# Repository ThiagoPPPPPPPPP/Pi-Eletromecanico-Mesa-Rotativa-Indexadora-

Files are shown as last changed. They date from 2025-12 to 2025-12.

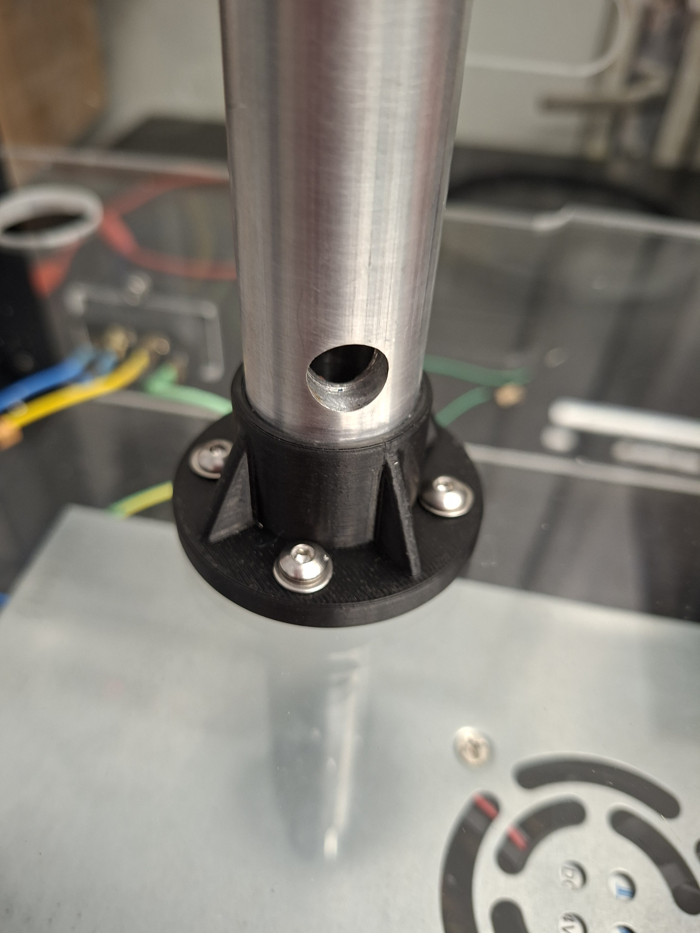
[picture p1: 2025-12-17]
Manual de Montagem/20251208_164349.jpg

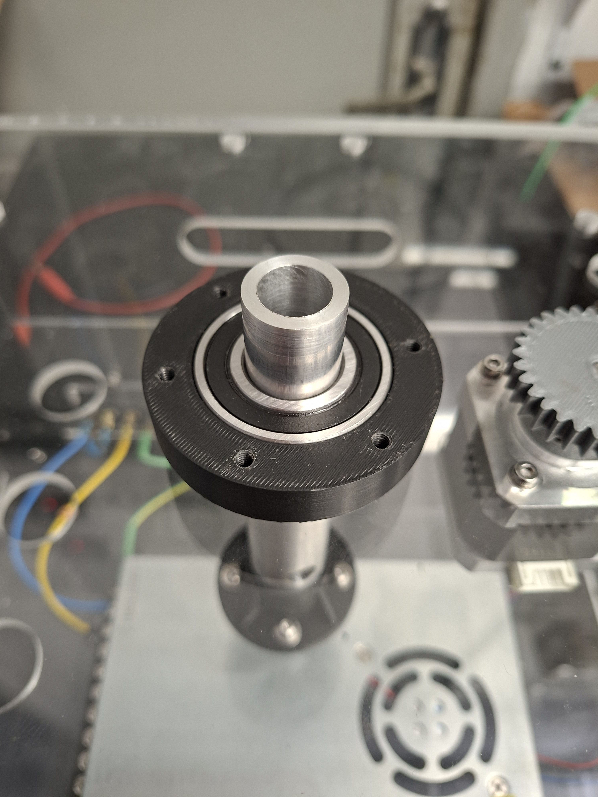
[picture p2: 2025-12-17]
Manual de Montagem/20251208_165738.jpg

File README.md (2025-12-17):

# Mesa Giratória Indexadora - Módulo de Ensino de Mecatrônica

Este repositório contém a documentação e os arquivos de projeto da **Mesa Giratória Indexadora**, um módulo de ensino desenvolvido para auxiliar na formação prática de alunos sobre integração de sistemas automatizados.

O projeto integra mecânica, eletrônica e programação para simular um processo industrial de indexação, detecção,  separação de peças ou possíveis operações em peças já catalogadas.

---

## 📖 Sobre o Projeto

A **Mesa Giratória Indexadora** foi projetada como um recurso pedagógico para demonstrar princípios de automação industrial, incluindo:
* Controle de posicionamento preciso.
* Sensoriamento e identificação de materiais.
* Atuação eletromecânica.
* Lógica de comando sequencial.

O sistema opera com uma tensão de segurança (5V a 24V) e possui uma estrutura transparente (acrílico) para permitir a visualização clara dos componentes e do funcionamento interno durante as aulas.

### ⚙️ Funcionalidades
* **Indexação Automática:** Movimentação da mesa em 6 posições fixas com parada precisa.
* **Detecção de Material:** Identificação de peças metálicas e não-metálicas (plástico) utilizando sensores indutivos e capacitivos.
* **Sistema de Expulsão:** Atuador solenoide customizado para remover peças da linha de produção após o processamento.
* **Interface Visual:** Feedback de status dos sensores e etapas do ciclo através de LEDs.
* **Segurança:** Operação em baixa tensão e botão de emergência.

---

## 🛠️ Hardware e Arquitetura

O projeto utiliza uma arquitetura dividida em **Nível Inferior** (Controle e Potência) e **Nível Superior** (Atuação e Processamento).

### Componentes Eletrônicos Principais
* **Controlador:** Arduino Mega 2560 R3.
* **Shield PLC:** Placa de adaptação DNMEB50 da eletechsup.
* **Atuadores:**
    * Motor de Passo NEMA 17.
    * Driver de Motor TB6600.
    * Solenoide Customizada (Ejeção).
    * Cooler 12V para refrigeração da eletrônica.
* **Sensores:**
    * Sensores Indutivos (Detecção de metal).
    * Sensores Capacitivos (Detecção de presença/não-metal).
* **Alimentação:** Fonte Chaveada 24V/15A.

### Estrutura Mecânica
* **Base e Caixa:** Acrílico 6mm (Corte a Laser).
* **Mesa Giratória:** Acrílico 4mm.
* **Peças de Suporte:** Impressão 3D (ABS) para suportes de sensores, solenoide e engrenagens.
* **Transmissão:** Sistema de Pinhão e Engrenagem Interna com redução 1:5.

---

## 💻 Software e Lógica

O firmware foi desenvolvido em **C++ (Arduino)** e implementa uma máquina de estados para controlar o ciclo da máquina:

1.  **Detecção:** Aguarda peça na estação de entrada.
2.  **Identificação:** Lê sensores para classificar o material (Metal/Não Metal).
3.  **Movimentação:** Aciona o motor de passo para avançar a mesa para a próxima estação.
4.  **Expulsão:** Ao chegar na estação de saída, ativa a solenoide se a peça for confirmada.
5.  **Feedback:** Atualiza os LEDs indicadores de status em tempo real.

---

## 📦 Como Reproduzir

### Pré-requisitos
* Arduino IDE instalado.
* Bibliotecas padrão do Arduino.

### Instalação
1.  Clone este repositório:
    ```bash
    git clone [https://github.com/ThiagoPPPPPPPPP/Pi-Eletromecanico-Mesa-Rotativa-Indexadora-.git](https://github.com/ThiagoPPPPPPPPP/Pi-Eletromecanico-Mesa-Rotativa-Indexadora-.git)
    ```
2.  Abra o arquivo principal do código (ex: `Mesa_Indexadora.ino`) na Arduino IDE.
3.  Conecte o Arduino Mega via USB.
4.  Selecione a placa **Arduino Mega or Mega 2560** no menu de ferramentas.
5.  Faça o upload do código.

> **Nota:** Consulte o arquivo `Manual de Montagem.pdf` para o passo a passo da montagem mecânica e o esquema elétrico detalhado no arquivo do relatório.

---

## 👥 Autores

Projeto desenvolvido por alunos do curso de **Engenharia Mecatrônica** do **IFSC - Câmpus Florianópolis**:

* **Gabriel Vitor Salasario Boing**
* **Jorge Henrique Martins de Oliveira Chaves**
* **Sarah Even Oliveira Barbosa Fernandes**
* **Thiago Paulo Pohlenz Piccoli de Oliveira**

---

## 🏫 Instituição

**Instituto Federal de Santa Catarina (IFSC)**
Departamento Acadêmico de Metal Mecânica
Florianópolis - 2025

---

*Este projeto é de cunho educacional e open-source.*

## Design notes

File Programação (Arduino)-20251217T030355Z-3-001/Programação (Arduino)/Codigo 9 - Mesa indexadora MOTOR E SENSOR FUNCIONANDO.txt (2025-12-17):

#include <Arduino.h>

// ======================================================
//                    MESA INDEXADORA 
// ======================================================

//V18 CAPACITIVO SAIDA
//V15 INDUTIVO ENTRADA
//V17 CAPACITIVO ENTRADA
//V16 INDUTIVO SAIDA

// ================================
//       SENSORES IND + CAP 
// ================================
#define SENIND1 66
#define SENIND2 67
#define SENC1   68
#define SENC2   69

// ================================
//               LEDS
// ================================
#define LED1 34
#define LED2 36
#define LED3 38
#define LED4 40

// ================================
//         SOLENOIDE 
// ================================
//#define CARGA    41
//#define TRIGGER  39

// ================================
//             MOTOR
// ================================
#define STEP_PIN   41
#define DIR_PIN    39
#define PASSOS_POR_POSICAO 1333
#define VELOCIDADE_US 800

// ================================
//           VARIÁVEIS
// ================================
bool pecas[6] = {0,0,0,0,0,0};
bool mesaLigada = false;
bool cicloAtivo = false;

unsigned long marcaTempo = 0;
const unsigned long tempoEtapa = 4000;

int v15 = 0, v16 = 0, v17 = 0, v18 = 0;

// forward declarations
void desligarTudo();
bool detectarPecaEntrada();
void ligarMesa();
void cicloIndexador();
int leituraMaterialEntrada();
int leituraMaterialSaida();
void expulsarPeca();
void finalizarCiclo();
void moverPosicao();
void moverEtapa(int pos);
void exibirStatus();
void IHM();

// ======================================================
//                     SETUP
// ======================================================
void setup() {
  Serial.begin(9600);
  delay(50);

  pinMode(SENIND1, INPUT);
  pinMode(SENIND2, INPUT);
  pinMode(SENC1, INPUT);
  pinMode(SENC2, INPUT);

  pinMode(LED1,OUTPUT);
  pinMode(LED2,OUTPUT);
  pinMode(LED3,OUTPUT);
  pinMode(LED4,OUTPUT);

  pinMode(CARGA,OUTPUT);
  pinMode(TRIGGER,OUTPUT);

  pinMode(STEP_PIN,OUTPUT);
  pinMode(DIR_PIN,OUTPUT);

  desligarTudo();
  Serial.println("==== SISTEMA PRONTO ====");
}

// ======================================================
//                        LOOP
// ======================================================
void loop(){  

  IHM();

  if(!mesaLigada && detectarPecaEntrada()){
      ligarMesa();
  }

  if(mesaLigada && cicloAtivo){
      cicloIndexador();
  }
}

// ======================================================
//              DETECTA PEÇA NA ENTRADA
// ======================================================
bool detectarPecaEntrada() {

  bool cap = digitalRead(SENC1);        // capacitivo
  bool ind = !digitalRead(SENIND1);      // indutivo

  if(cap == HIGH || ind == HIGH){       // qualquer um detectou → peça presente
      pecas[0] = 1;

      Serial.print("\n📥 Peça detectada na ENTRADA: ");

      if(ind == HIGH){
          Serial.println("METAL");
      } 
      else if(ind == LOW && cap == HIGH){
          Serial.println("NAO METAL");
      }
      else {
          Serial.println("SEM LEITURA");
      }

      return true;
  }

  return false;
}

// ======================================================
//                   LIGAR MESA
// ======================================================
void ligarMesa(){
  Serial.println("\n▶ Iniciando ciclo...");
  mesaLigada = true;
  cicloAtivo = true;
  marcaTempo = millis();
}

// ======================================================
//                   CICLO COMPLETO 
// ======================================================
void cicloIndexador(){
  static int etapa = 0;

  if(millis()-marcaTempo < tempoEtapa) return;
  marcaTempo = millis();

  switch(etapa){
    case 0:
      moverEtapa(1); 
      break; 
    case 1:
      moverEtapa(2); 
      break; 
    case 2:
      moverEtapa(3); 
      break;
    case 3:
      moverEtapa(4);
      break;
    case 4:
      moverEtapa(5);

      // → POSIÇÃO 6 (Saída)
      expulsarPeca();  
      finalizarCiclo(); 
      etapa = 0;
      return;

    default:
      etapa=0; 
      return;
  }

  etapa++;
}

// ======================================================
//       LEITURA DO MATERIAL NA SAÍDA (POSIÇÃO 6)
// ======================================================
int leituraMaterialSaida(){

  bool cap = digitalRead(SENC2);
  bool ind = !digitalRead(SENIND2);

  if(ind == HIGH){
     Serial.println("📦 Saída → METAL");
     return 1;
  } 
  else if(ind == LOW && cap == HIGH){
     Serial.println("📦 Saída → NAO METAL");
     return 2;
  }
  else {
     Serial.println("📦 Saída → SEM PEÇA");
     return 0;
  }
}

// ======================================================
//                EXPULSÃO FINAL
// ======================================================
void expulsarPeca(){

  Serial.println("\n⏳ Checando peça na posição final...");

  int material = leituraMaterialSaida();

  bool cap = digitalRead(SENC2);
  bool ind = !digitalRead(SENIND2);

  if(cap == HIGH || ind == HIGH){
    Serial.println("✔ Peça confirmada na SAÍDA. Acionando solenoide...");

    digitalWrite(CARGA, HIGH);
    delay(150);
    digitalWrite(TRIGGER, HIGH);
    delay(150);
    digitalWrite(TRIGGER, LOW);
    digitalWrite(CARGA, LOW);

    Serial.println("➡ Peça expulsa.");
  } 
  else {
    Serial.println("⚠ Nenhuma peça encontrada para expulsar.");
  }
}

// ======================================================
//                   FINALIZAR CICLO
// ======================================================
void finalizarCiclo(){
  Serial.println("\n✔ Ciclo completo. Sistema aguardando nova peça.");
  cicloAtivo=false;
  mesaLigada=false;
  desligarTudo();
}

// ======================================================
//                   MOTOR — 1 POSIÇÃO
// ======================================================
void moverPosicao(){
  digitalWrite(DIR_PIN,LOW);
  for(int i=0;i<PASSOS_POR_POSICAO;i++){
    digitalWrite(STEP_PIN,HIGH); delayMicroseconds(VELOCIDADE_US);
    digitalWrite(STEP_PIN,LOW);  delayMicroseconds(VELOCIDADE_US);
  }
}

// desloca vetor de posição
void moverEtapa(int pos){
  moverPosicao();
  for(int i=5;i>0;i--) pecas[i] = pecas[i-1];
  pecas[0]=0;
  Serial.print("\n➡ Mesa avançou para posição ");
  Serial.println(pos+1);
  exibirStatus();
}

// ======================================================
//              MOSTRAR STATUS NO SERIAL
// ======================================================
void exibirStatus(){
  Serial.print("Estado da mesa: ");
  for(int i=0;i<6;i++){ Serial.print(pecas[i]); Serial.print(" "); }
  Serial.println();
}

// ======================================================
//                       IHM
// ======================================================
void IHM() {
  v15 = digitalRead(SENIND1);
  v16 = digitalRead(SENIND2);
  v17 = digitalRead(SENC1);
  v18 = digitalRead(SENC2);

  if (v15 != 1 && v16 == 1 && v17 == 0 && v18 == 0) {
    digitalWrite(LED1, LOW);
    digitalWrite(LED2, HIGH);
    digitalWrite(LED3, HIGH);
    digitalWrite(LED4, HIGH);
  } else if (v15 != 1 && v16 != 1 && v17 == 0 && v18 == 0) {
    digitalWrite(LED1, HIGH);
    digitalWrite(LED2, LOW);
    digitalWrite(LED3, HIGH);
    digitalWrite(LED4, HIGH);
  } else if (v15 == 1 && v16 == 1 && v17 != 0 && v18 == 0) {
    digitalWrite(LED1, HIGH);
    digitalWrite(LED2, HIGH);
    digitalWrite(LED3, LOW);
    digitalWrite(LED4, HIGH);
  } else if (v15 == 1 && v16 == 1 && v17 == 0 && v18 != 0) {
    digitalWrite(LED1, HIGH);
    digitalWrite(LED2, HIGH);
    digitalWrite(LED3, HIGH);
    digitalWrite(LED4, LOW);
  } else {
    digitalWrite(LED1, HIGH);
    digitalWrite(LED2, HIGH);
    digitalWrite(LED3, HIGH);
    digitalWrite(LED4, HIGH);
  }
}

// ======================================================
//             RESET EM TODAS SAIDAS/LEDS
// ======================================================
void desligarTudo(){
  digitalWrite(CARGA,LOW);
  digitalWrite(TRIGGER,LOW);
  digitalWrite(LED1,HIGH);
  digitalWrite(LED2,HIGH);
  digitalWrite(LED3,HIGH);
  digitalWrite(LED4,HIGH);
}

// ======================================================
//           MÓDULOS EM BRANCO PARA UPGRADES FUTUROS
// ======================================================
void moduloExtra1() {}
void moduloExtra2() {}
void moduloExtra3() {}
void moduloExtra4() {}
// ======================================================
// ======================================================

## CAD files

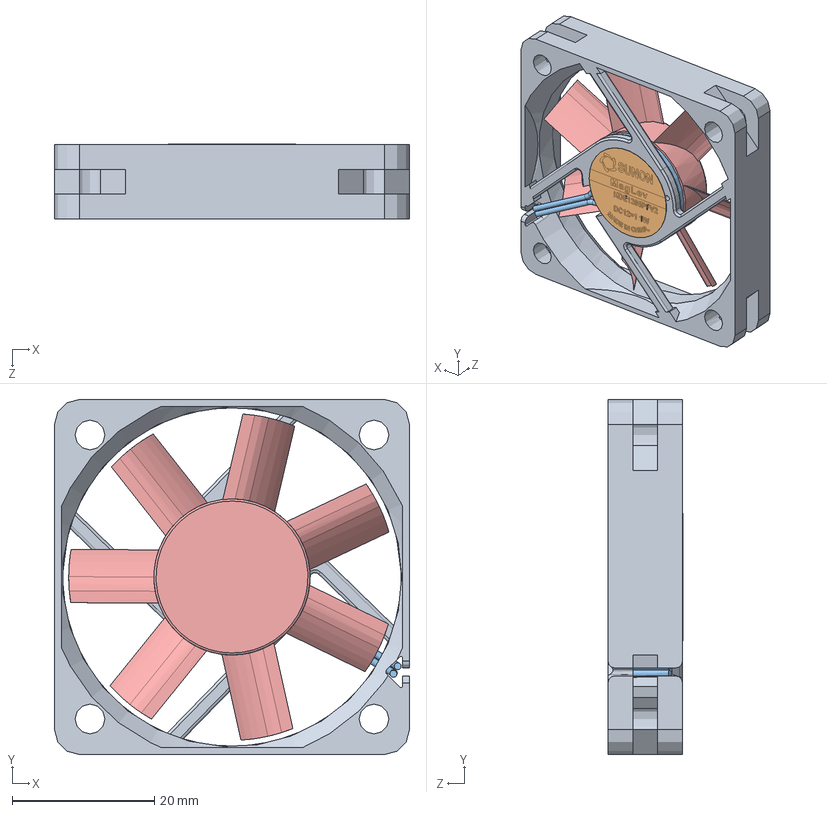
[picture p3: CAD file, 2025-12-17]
Arquivos CAD-20251217T030342Z-3-001/Arquivos CAD/Peças e Montagem Final/Cooler 50x50x10.5/Cooler 50x50x10.5 detailed SBORKA.SLDASM
50.0 x 50.0 x 10.6 mm
Cooler 50x50x10.5 body
Sticker SUNON
Cooler pcb
Cooler Motor
Cooler Blades

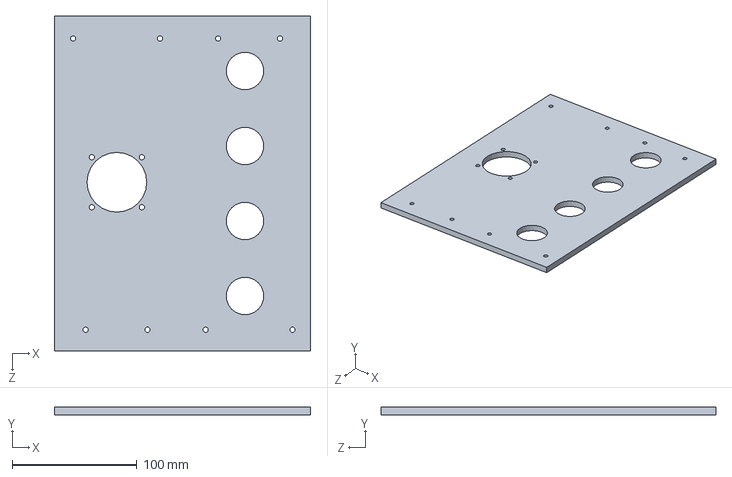
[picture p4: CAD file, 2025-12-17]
Arquivos CAD-20251217T030342Z-3-001/Arquivos CAD/Peças e Montagem Final/Caixa Parafusada/Lateral_cooler_parafusado.SLDPRT
205.0 x 6.00 x 268.0 mm

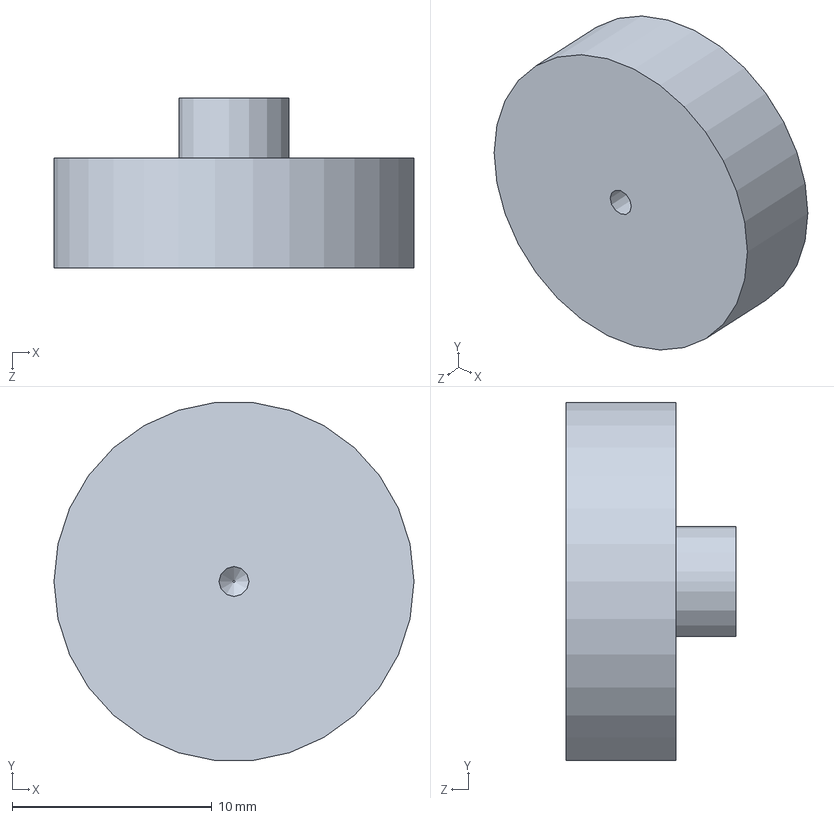
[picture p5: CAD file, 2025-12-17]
Arquivos CAD-20251217T030342Z-3-001/Arquivos CAD/Peças e Montagem Final/Cooler 50x50x10.5/Cooler Motor.SLDPRT
18.0 x 17.9 x 8.50 mm

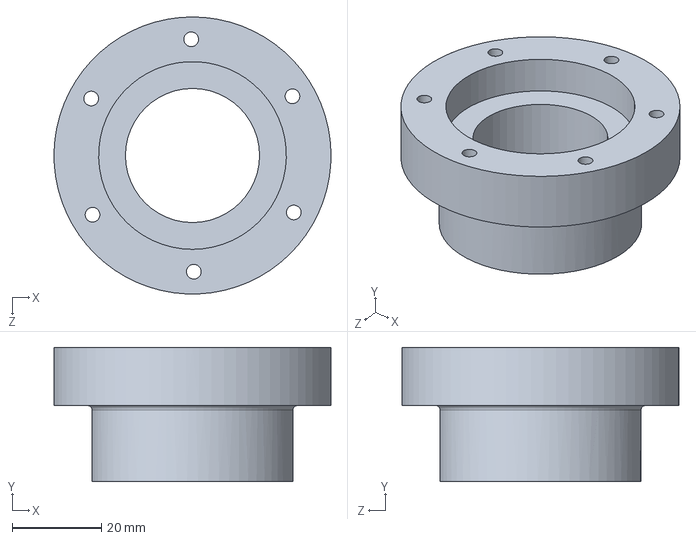
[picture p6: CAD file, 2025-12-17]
Arquivos CAD-20251217T030342Z-3-001/Arquivos CAD/Peças e Montagem Final/Mesa Giratória/Luva (mancal).SLDPRT
62.0 x 30.0 x 62.0 mm

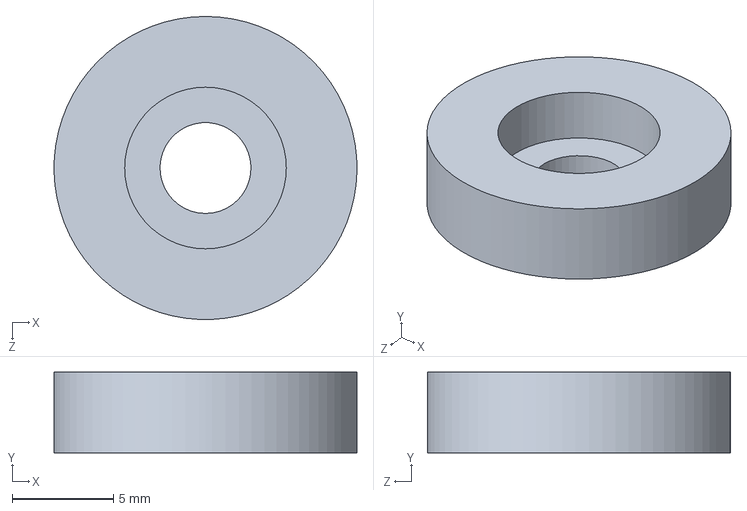
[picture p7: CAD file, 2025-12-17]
Arquivos CAD-20251217T030342Z-3-001/Arquivos CAD/Peças e Montagem Final/Caixa Parafusada/Pé_Fundo.SLDPRT
15.0 x 4.00 x 15.0 mm

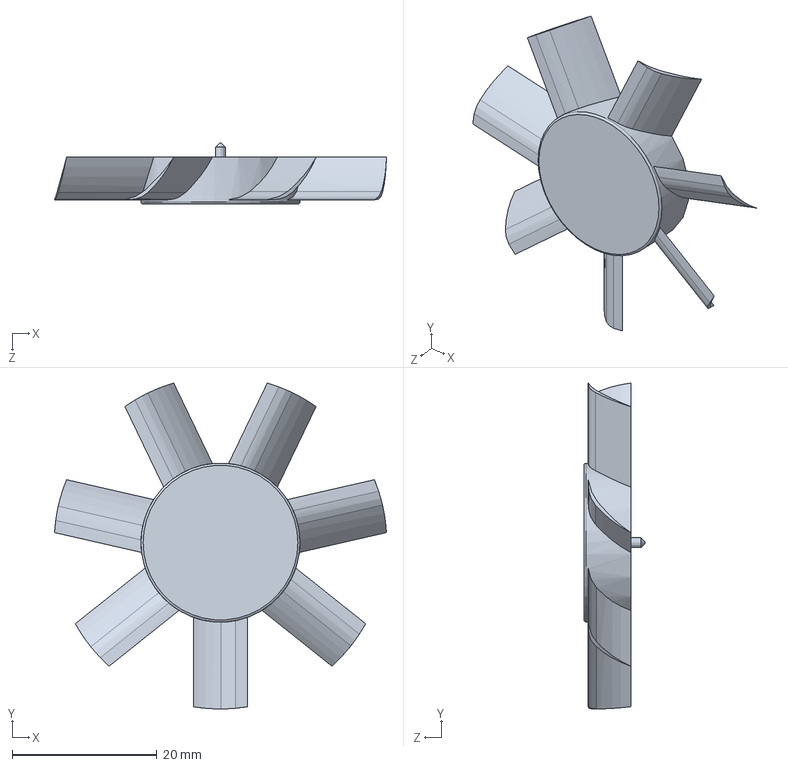
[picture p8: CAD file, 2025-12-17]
Arquivos CAD-20251217T030342Z-3-001/Arquivos CAD/Peças e Montagem Final/Cooler 50x50x10.5/Cooler Blades.SLDPRT
45.9 x 45.1 x 8.50 mm

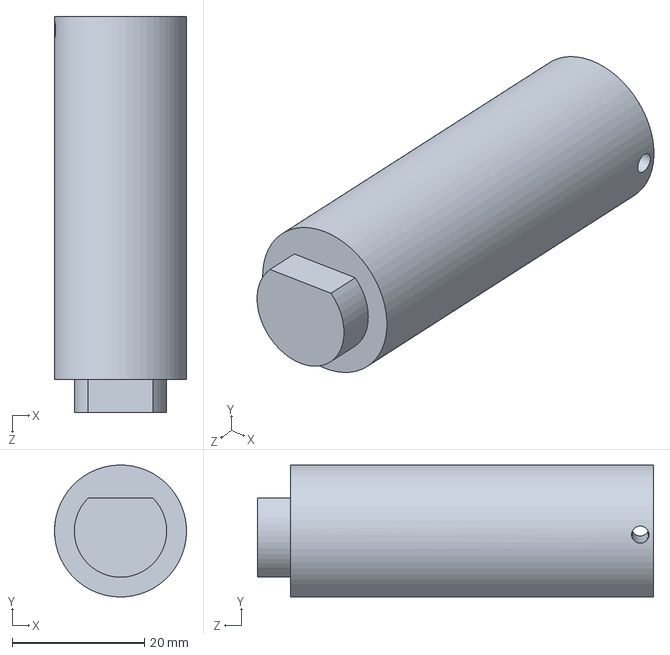
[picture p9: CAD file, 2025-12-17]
Arquivos CAD-20251217T030342Z-3-001/Arquivos CAD/Peças e Montagem Final/Embulo Solenoide.SLDPRT
20.0 x 20.0 x 60.0 mm

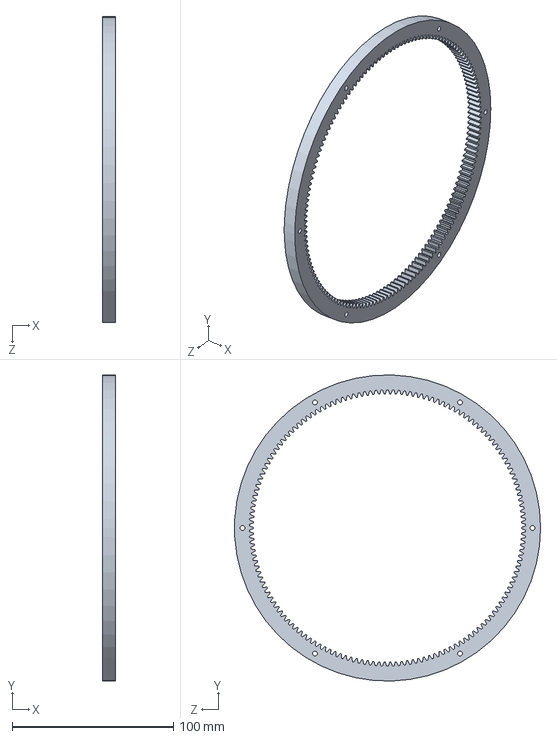
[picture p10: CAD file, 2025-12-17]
Arquivos CAD-20251217T030342Z-3-001/Arquivos CAD/Peças e Montagem Final/Mesa Giratória/Eng Interna M1.125 D150.SLDPRT
8.00 x 189.9 x 190.0 mm

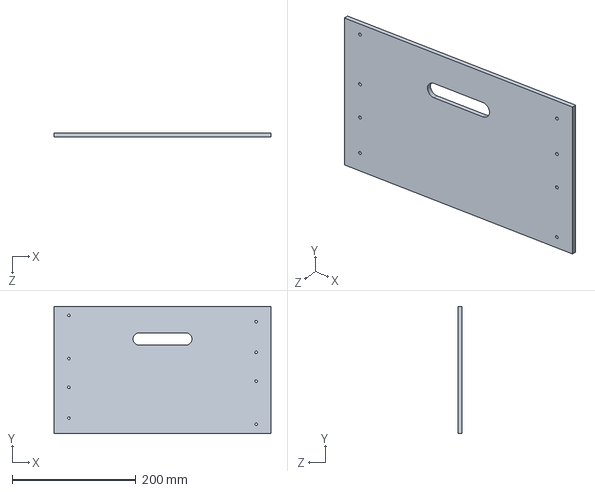
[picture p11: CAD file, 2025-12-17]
Arquivos CAD-20251217T030342Z-3-001/Arquivos CAD/Peças e Montagem Final/Caixa Parafusada/Frente-Back_parafusado.SLDPRT
350.0 x 205.0 x 6.00 mm

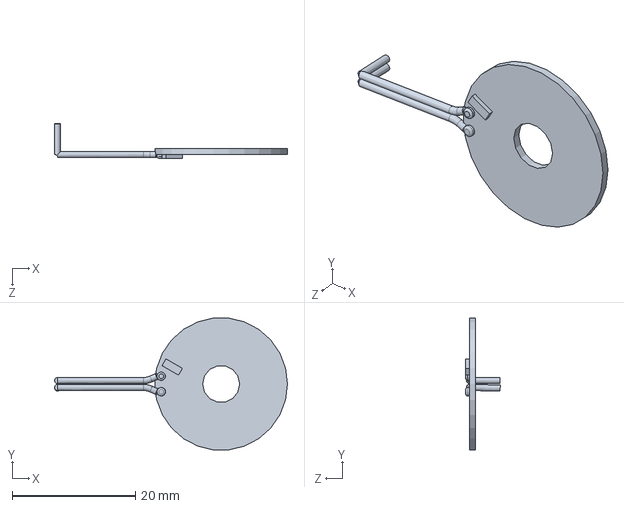
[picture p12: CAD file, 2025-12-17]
Arquivos CAD-20251217T030342Z-3-001/Arquivos CAD/Peças e Montagem Final/Cooler 50x50x10.5/Cooler pcb.SLDPRT
37.8 x 21.3 x 5.61 mm

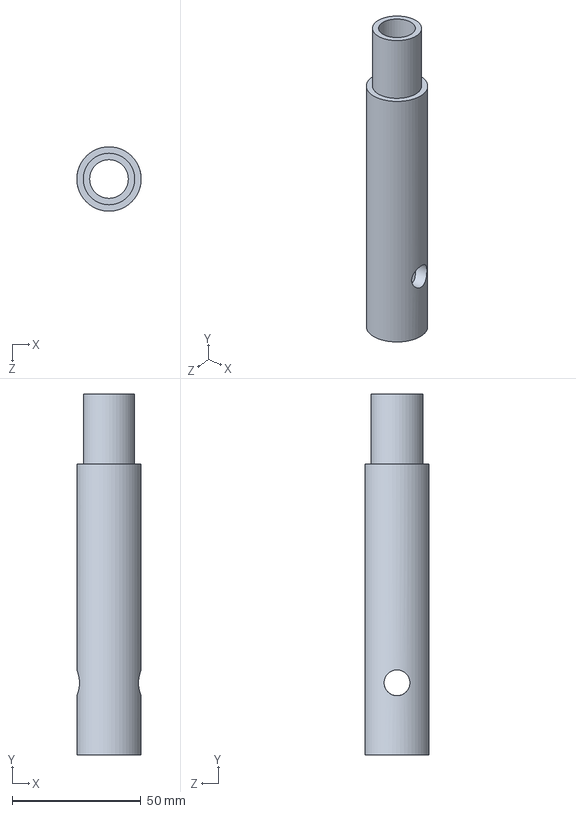
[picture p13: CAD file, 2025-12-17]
Arquivos CAD-20251217T030342Z-3-001/Arquivos CAD/Peças e Montagem Final/Mesa Giratória/Eixo.SLDPRT
25.0 x 140.0 x 25.0 mm

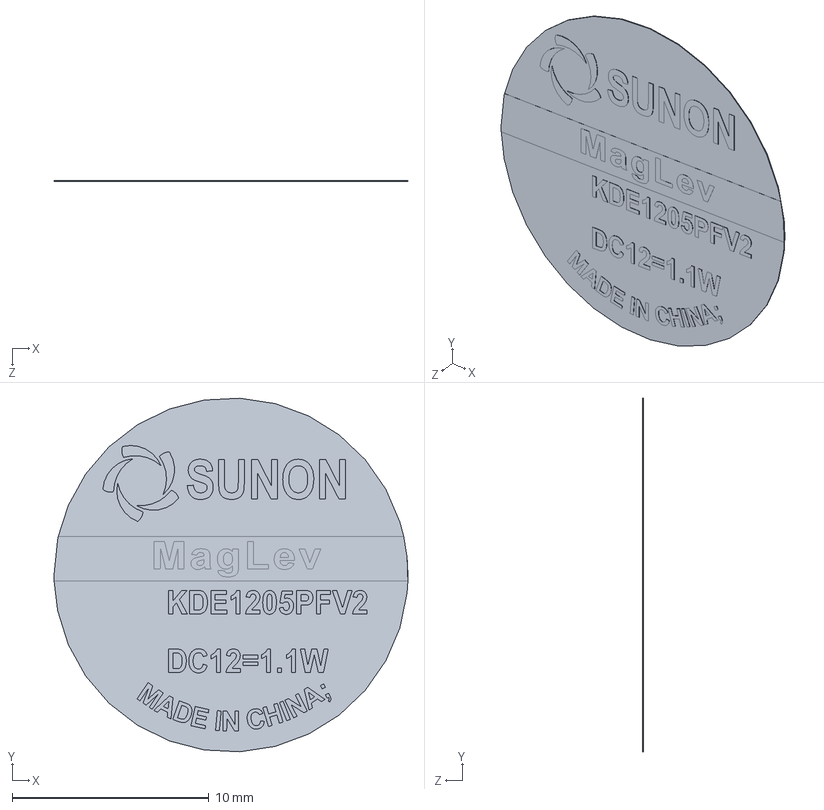
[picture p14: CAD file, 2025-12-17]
Arquivos CAD-20251217T030342Z-3-001/Arquivos CAD/Peças e Montagem Final/Cooler 50x50x10.5/Sticker SUNON.SLDPRT
18.0 x 18.0 x 0.07 mm

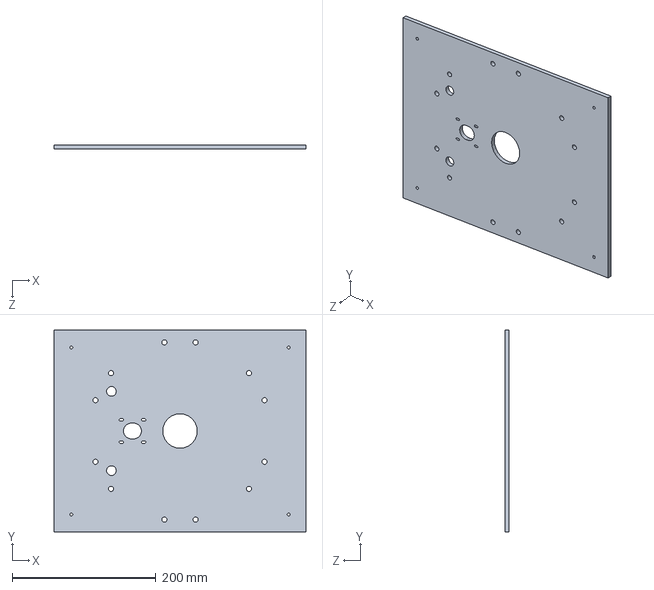
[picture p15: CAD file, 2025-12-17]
Arquivos CAD-20251217T030342Z-3-001/Arquivos CAD/Peças e Montagem Final/Caixa Parafusada/Top_parafusado.SLDPRT
350.0 x 280.0 x 6.00 mm

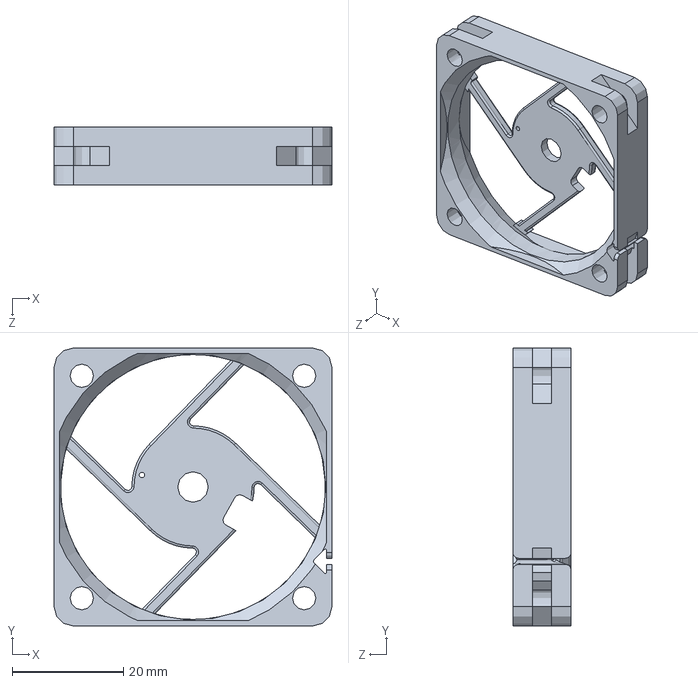
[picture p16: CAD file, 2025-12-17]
Arquivos CAD-20251217T030342Z-3-001/Arquivos CAD/Peças e Montagem Final/Cooler 50x50x10.5/Cooler 50x50x10.5 body.SLDPRT
50.0 x 50.0 x 10.5 mm

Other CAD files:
Arquivos CAD-20251217T030342Z-3-001/Arquivos CAD/Peças e Montagem Final/Caixa Parafusada/Mont_caixa_parafusada.SLDASM
Arquivos CAD-20251217T030342Z-3-001/Arquivos CAD/Peças e Montagem Final/Fonte 24V.SLDPRT
Arquivos CAD-20251217T030342Z-3-001/Arquivos CAD/Peças e Montagem Final/Caixa Parafusada/Frente-Back_parafusado_fonte.SLDPRT
Arquivos CAD-20251217T030342Z-3-001/Arquivos CAD/Peças e Montagem Final/Caixa Parafusada/Lateral_parafusado.SLDPRT
Arquivos CAD-20251217T030342Z-3-001/Arquivos CAD/Peças e Montagem Final/Anterior da Solenoide.f3d
Arquivos CAD-20251217T030342Z-3-001/Arquivos CAD/Peças e Montagem Final/Caixa Parafusada/1 andar.SLDPRT
Arquivos CAD-20251217T030342Z-3-001/Arquivos CAD/Peças e Montagem Final/Caixa Parafusada/Fundo_parafusado.SLDPRT
Arquivos CAD-20251217T030342Z-3-001/Arquivos CAD/Peças e Montagem Final/Caixa Parafusada/cantoneira2.SLDPRT
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

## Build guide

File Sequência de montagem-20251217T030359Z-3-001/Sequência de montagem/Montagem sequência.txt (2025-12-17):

Caixa componentes:

-Fundo_parafusado;
-Lateral_cooler_parafusado;
-Lateral parafusado;
-Frente-Back_parafusado;
-Frente-Back_parafusado_fonte;
-Top_parafusado;
-1 andar;
-Placa de controle;
-TB-6600;
-8 cantoneiras;
-Fonte 24V;
-Cooler;

Mesa componentes:

-Mesa inteira
-6 Ressalto Peça;
-Motor de passo;
-Luva(mancal);
-Rolamento;
-2 Sensores indutivos;
-Suporte eixo;
-Eixo;
-Solenoide
-Eng interna M1.125 D150;
-Pinhão m1.125 D30;
-Suporte solenoide com viga v2.step;

Montagem:

-Parte inferior:
1_ 4 cantoneiras entre parte media e base inferior;
2_ 20 parasusos M4 (4 para fixar Fundo_parafusado e cantoneira, 16 para fixar cantoneira e faces laterais);
3_ Fonte 24V;
4_ 2 parafusos diâmetro 4.2mm para fixar Fonte 24V na parte Frente-Back_parafusado_fonte;
5_ Cooler;
6_ 4 parafusos diâmetro 4.2mm para fixar Cooler na parte Lateral_cooler_parafusado;

-Parte média:
1_ 2 parafusos M4 para fixar cantoneira inferior->1 andar->cantoneira superior;
2_ 4 cantoneiras entre parte media e parte superior;
3_ 16 parafusos M4 para fixar cantoneiras as faces laterais ;
4_ Placa de controle;
5_ TB-6600;
6_ Eixo
7_ Suporte Eixo
8_ 4 parafusos M4 para fixar Suporte Eixo em 1 andar;

Mesa semi-completa:

1_ 12 parafusos M4 para fixar 6 ressalto peça em Mesa inteira;
2_ Rolamento
3_ 6 parafusos M4 para fixar Luva(mancal) em Mesa inteira;
4_ 6 parafusos M3 para fixar Eng interna M1.125 D150 em Mesa inteira;

-Parte superior:
1_ 2 parafusos M4 para fixar cantoneira superior->Top_parafusado;
2_ 2 sensores capacitivo (fixar no Top_parafusado pela porca do sensor com a furação da mesa);
3_ Motor de passo;
4_ Posicionar Suporte solenoide com viga v2.step no Eixo;
5_ 4 parafusos M3 para fixar Motor de passo no Top_parafusado;
6_ Posicionar Eng interna M1.125 D150 com pinhão m1.125 D30
7_ Posicionar Mesa inteira no Eixo;

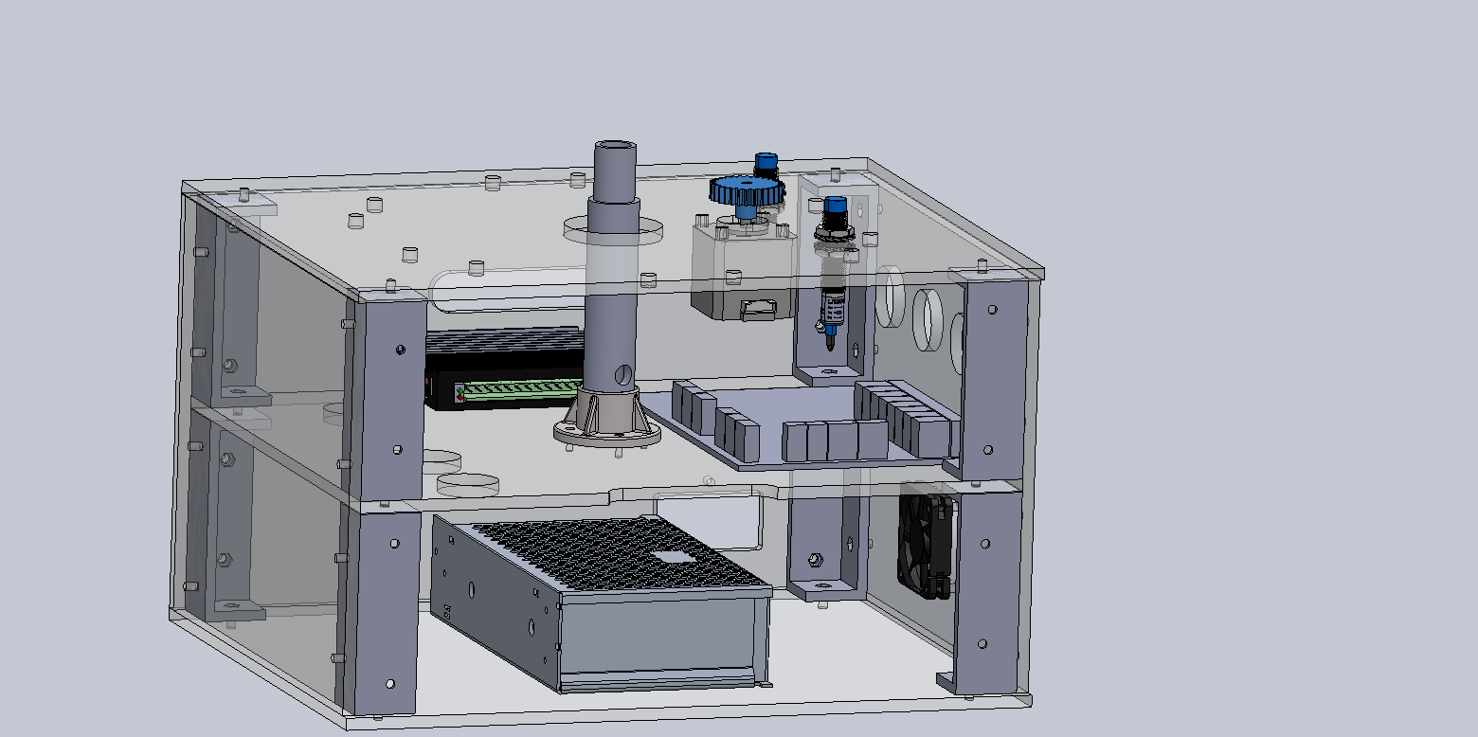
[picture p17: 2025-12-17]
Sequência de montagem-20251217T030359Z-3-001/Sequência de montagem/17-Posicionar e fixar o inhao m1.125 D30 no motor de passo.png

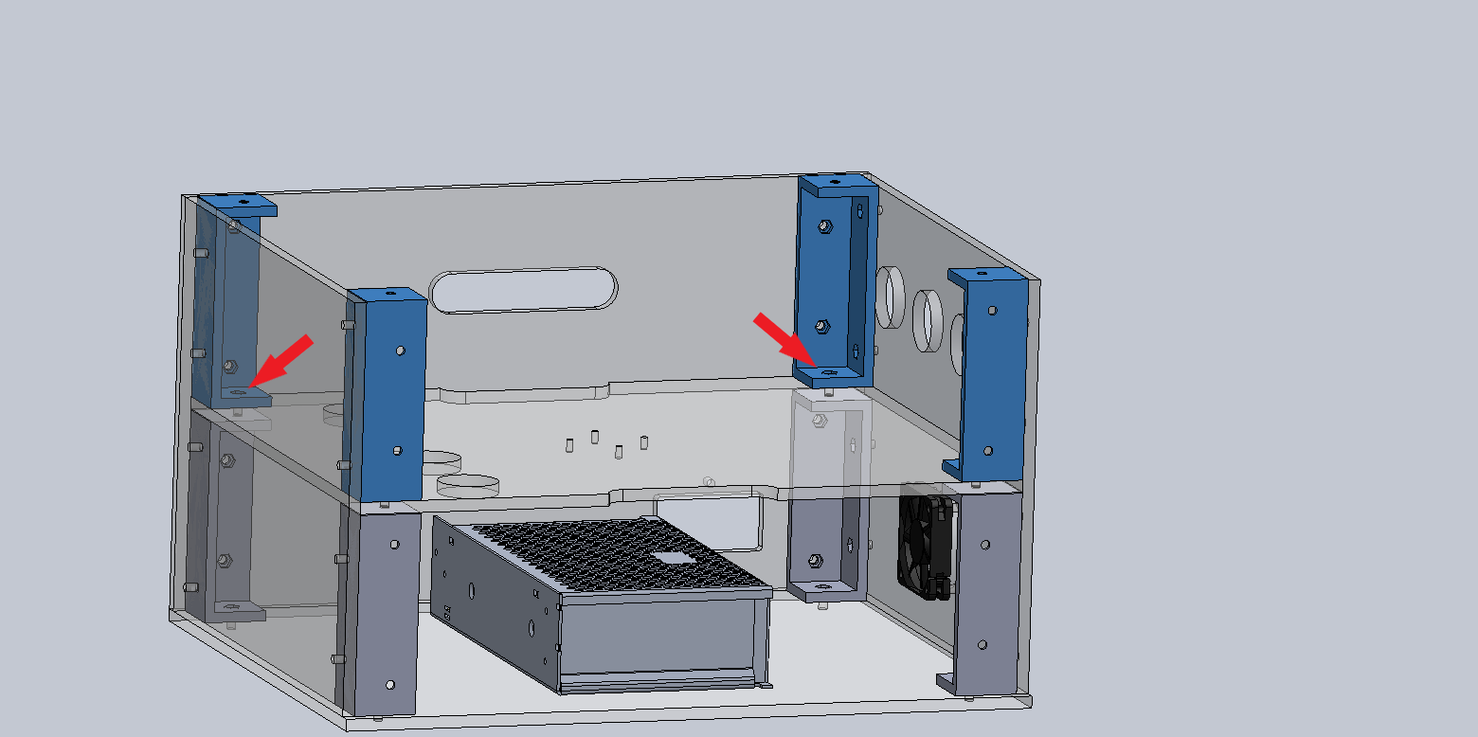
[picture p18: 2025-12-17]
Sequência de montagem-20251217T030359Z-3-001/Sequência de montagem/9-Posicionar e fixar as cantoneiras nas laterais e nas cantoneiras inferiores_Setas.png

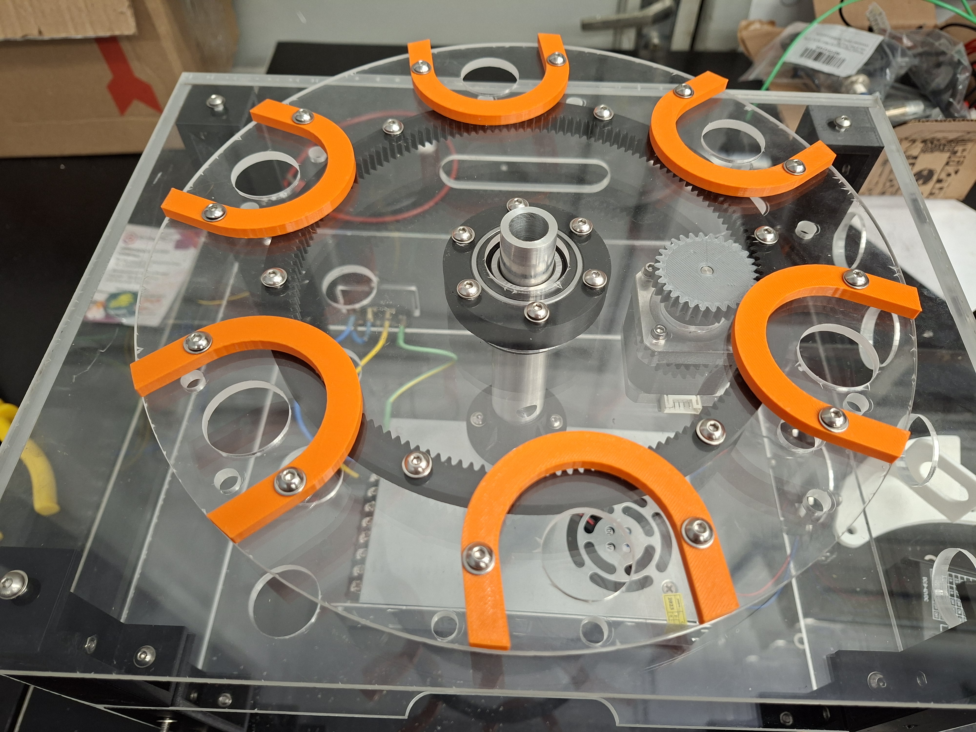
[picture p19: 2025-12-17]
Manual de Montagem/20251208_170824.jpg

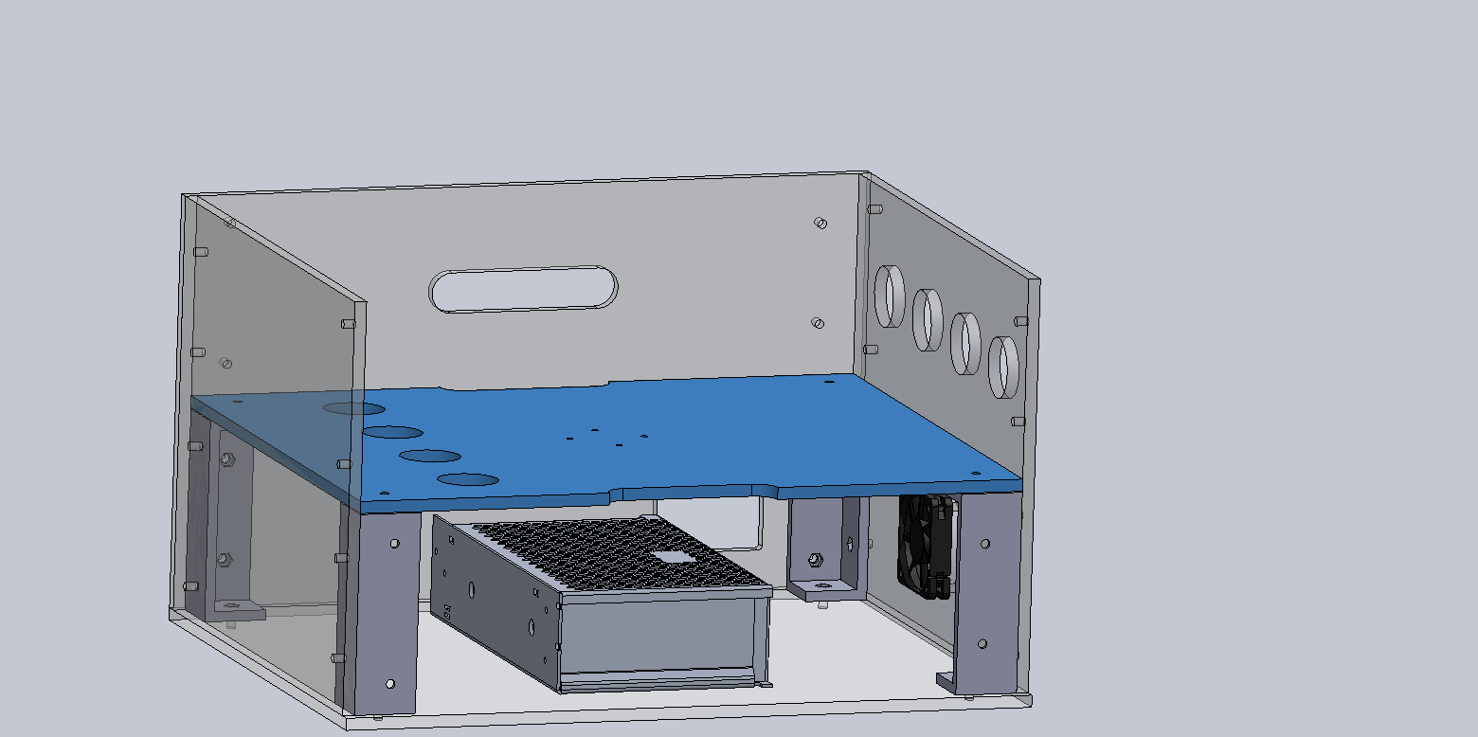
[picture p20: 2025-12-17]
Sequência de montagem-20251217T030359Z-3-001/Sequência de montagem/8-Posicionar o 1 andar na parte superior das cantoneiras.png

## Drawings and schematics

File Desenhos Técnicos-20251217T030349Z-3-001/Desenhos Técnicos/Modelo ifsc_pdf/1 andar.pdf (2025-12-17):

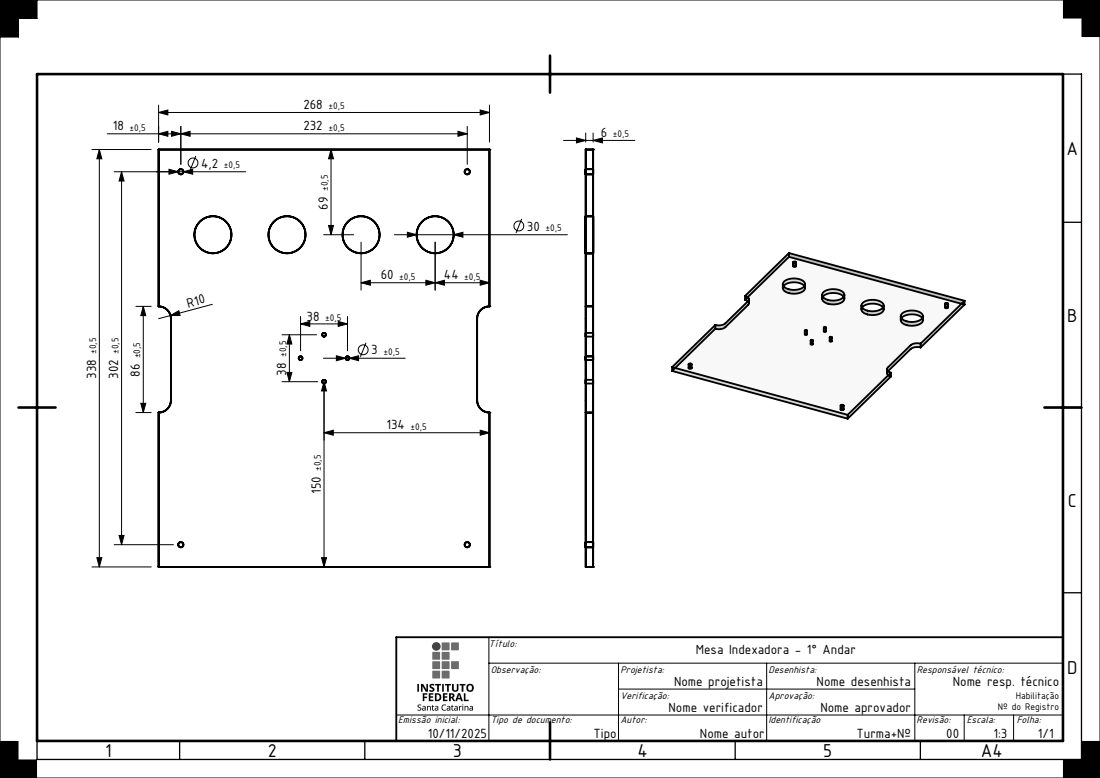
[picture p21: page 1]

Título: Mesa Indexadora - 1° Andar

Observação: | Projetista: Nome projetista | Desenhista: Nome desenhista | Responsável técnico: Nome resp. técnico Habilitação Nº do Registro

Verificação: Nome verificador | Aprovação: Nome aprovador

Emissão inicial: 10/11/2025 | Tipo de documento: | | Autor: Nome autor | Identificação Turma+Nº | Revisão: 00 | Escala: 1:3 | Folha: 1/1

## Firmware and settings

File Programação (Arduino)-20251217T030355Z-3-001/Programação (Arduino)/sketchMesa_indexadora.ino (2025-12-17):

// ======================================================
//                      MESA INDEXADORA 
// ======================================================

// ================================
//      ENTRADAS (DNME B50)
// ================================
#define BTN_INICIO 22         // IN1
#define BTN_SAIDA 23          // IN2
#define SENSOR_INDUTIVO 24    // IN3
#define SENSOR_CAPACITIVO 25  // IN4

// ================================
//        SAIDAS (DNME B50)
// ================================
#define OP1 30
#define OP2 31
#define OP3 32
#define OP4 33
#define OP_SAIDA 34

#define LED_STATUS 13

// ================================
//      MOTOR DE PASSO (A4988)
// ================================
#define STEP_PIN 4
#define DIR_PIN 5
#define ENABLE_PIN 6

// ================================
//            COOLER
// ================================
#define COOLER_PIN 9                  // Pinagem (PWM)
int coolerVelocidade = 180;           // 0–255 (70% velocidade)

// Ajustar o motor real
const int PASSOS_POR_POSICAO = 533;

// posicoes[i]:
//   0 = vazio
//   1 = peça metálica
//   2 = peça não metálica
int posicoes[6] = { 0, 0, 0, 0, 0, 0 };

// ================================
//            CONTROLE
// ================================
bool mesaLigada = false;
bool cicloAtivo = false;

unsigned long tempoAnterior = 0;
const unsigned long intervalo = 3000;

// ======================================================
//                         SETUP
// ======================================================
void setup() {
  Serial.begin(9600);

  pinMode(BTN_INICIO, INPUT_PULLUP);
  pinMode(BTN_SAIDA, INPUT_PULLUP);

  pinMode(SENSOR_INDUTIVO, INPUT);
  pinMode(SENSOR_CAPACITIVO, INPUT);

  pinMode(LED_STATUS, OUTPUT);

  pinMode(OP1, OUTPUT);
  pinMode(OP2, OUTPUT);
  pinMode(OP3, OUTPUT);
  pinMode(OP4, OUTPUT);
  pinMode(OP_SAIDA, OUTPUT);

  // MOTOR DE PASSO
  pinMode(STEP_PIN, OUTPUT);
  pinMode(DIR_PIN, OUTPUT);
  pinMode(ENABLE_PIN, OUTPUT);
  digitalWrite(ENABLE_PIN, LOW);

  // COOLER
  pinMode(COOLER_PIN, OUTPUT);
  analogWrite(COOLER_PIN, 0);   // cooler inicia desligado

  desligarSaidas();

  Serial.println("==== SISTEMA PRONTO ====");
}

// ======================================================
//                      LOOP PRINCIPAL
// ======================================================
void loop() {

  if (digitalRead(BTN_INICIO) == LOW && !mesaLigada) {
    ligarMesa();
    delay(300);
  }

  if (mesaLigada && cicloAtivo) {
    executarCiclo();
  }

  if (digitalRead(BTN_SAIDA) == LOW && mesaLigada) {
    expulsarPeca();
    desligarMesa();
    delay(300);
  }
}

// ======================================================
//                     LIGAR A MESA
// ======================================================
void ligarMesa() {
  mesaLigada = true;
  cicloAtivo = true;

  digitalWrite(LED_STATUS, HIGH);

  Serial.println("Mesa ligada.");
  Serial.println("Cooler ativo.");        // <<< mensagem
  analogWrite(COOLER_PIN, coolerVelocidade);  // <<< liga cooler

  Serial.println("Inserindo peça na posição 1…");

  rotacionarMesa();

  posicoes[0] = 1;
  exibirPosicoes();

  tempoAnterior = millis();
}

// ======================================================
//                 CICLO COMPLETO
// ======================================================
void executarCiclo() {
  static int etapa = 0;

  if (millis() - tempoAnterior < intervalo) return;
  tempoAnterior = millis();

  switch (etapa) {

    case 0:
      Serial.println("Posição 2…");
      rotacionarMesa();
      break;

    case 1:
      Serial.println("Posição 3…");
      rotacionarMesa();
      break;

    case 2:
      Serial.println("Posição 4 – leitura de material…");
      rotacionarMesa();
      lerMaterial(3);
      break;

    case 3:
      Serial.println("Posição 5 – leitura de material…");
      rotacionarMesa();
      lerMaterial(4);
      break;

    case 4:
      Serial.println("Posição 6 – expulsão da peça.");
      rotacionarMesa();
      expulsarPeca();
      cicloAtivo = false;
      desligarMesa();
      etapa = 0;
      return;

    default:
      etapa = 0;
      return;
  }

  exibirPosicoes();
  etapa++;
}

// ======================================================
//                   LEITURA DOS SENSORES
// ======================================================
void lerMaterial(int indice) {

  bool metal = digitalRead(SENSOR_INDUTIVO);
  bool naoMetal = digitalRead(SENSOR_CAPACITIVO);

  if (metal) {
    posicoes[indice] = 1;
    Serial.println(" → Peça metálica identificada.");
  } else if (naoMetal) {
    posicoes[indice] = 2;
    Serial.println(" → Peça não metálica identificada.");
  } else {
    Serial.println(" → Sensor não detectou material.");
  }
}

// ======================================================
//                      EXPULSAR A PEÇA
// ======================================================
void expulsarPeca() {
  Serial.println("Expulsando peça…");

  digitalWrite(OP_SAIDA, HIGH);
  delay(800);
  digitalWrite(OP_SAIDA, LOW);

  posicoes[5] = 0;
}

// ======================================================
//                     DESLIGAR A MESA
// ======================================================
void desligarMesa() {
  mesaLigada = false;
  cicloAtivo = false;

  analogWrite(COOLER_PIN, 0);   // <<< cooler desligado

  desligarSaidas();

  Serial.println("Mesa desligada. Aguardando novo ciclo.");
  Serial.println("Cooler desativado");
}

// ======================================================
//              DESLIGAR TODAS AS SAÍDAS
// ======================================================
void desligarSaidas() {
  digitalWrite(LED_STATUS, LOW);

  digitalWrite(OP1, LOW);
  digitalWrite(OP2, LOW);
  digitalWrite(OP3, LOW);
  digitalWrite(OP4, LOW);
  digitalWrite(OP_SAIDA, LOW);
}

// ======================================================
//           MOVER MOTOR UMA POSIÇÃO REAL
// ======================================================
void moverMotorUmaPosicao() {

  digitalWrite(DIR_PIN, HIGH);

  for (int i = 0; i < PASSOS_POR_POSICAO; i++) {
    digitalWrite(STEP_PIN, HIGH);
    delayMicroseconds(800);
    digitalWrite(STEP_PIN, LOW);
    delayMicroseconds(800);
  }
}

// ======================================================
//                   ROTACIONAR A MESA
// ======================================================
void rotacionarMesa() {

  moverMotorUmaPosicao();

  int ultimo = posicoes[5];
  for (int i = 5; i > 0; i--) {
    posicoes[i] = posicoes[i - 1];
  }
  posicoes[0] = ultimo;

  Serial.println("Mesa rotacionada 1 posição.");
}

// ======================================================
//           MÓDULOS EM BRANCO PARA UPGRADES FUTUROS
// ======================================================
void moduloExtra1() {}
void moduloExtra2() {}
void moduloExtra3() {}
void moduloExtra4() {}
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

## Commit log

2025-12-17 Add files via upload
    Arquivos CAD e Programação
    [1 andar.SLDPRT, Anterior da Solenoide.f3d, Cooler 50x50x10.5 body.SLDPRT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]
2025-12-17 Add files via upload
    Desenhos Técnicos
    [1 andar.SLDDRW, Eixo.SLDDRW, Eng Interna M1.125 D150.SLDDRW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]
2025-12-17 Add files via upload
    Sequência de Montagem
2025-12-17 Add files via upload
    Primeira parte Manual de Montagem
2025-12-17 Add files via upload
    Segunda parte do Manual de Montagem
2025-12-17 Add files via upload
    Terceira parte do Manual de Montagem
2025-12-17 Add files via upload
    Ultima parte do Manual de Montagem
2025-12-17 Delete Programação (Arduino)-20251217T030355Z-3-001/Programação (Arduino)/Esquematico eletrico e de Pinagem.png
    Exclusão do Esquema Antigo
2025-12-17 Add files via upload
    vídeo com algumas etapas de fabricação e teste
